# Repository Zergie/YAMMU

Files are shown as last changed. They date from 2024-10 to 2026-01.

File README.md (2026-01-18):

 <!--![GitHub Release](https://img.shields.io/github/v/release/Zergie/YAMMU)-->
Discord Shield (https://discord.gg/QSjW5CMHZC)



# Yet Another MMU
"Eight Materials, Twin Drawers, One Enclosure."

A Multi-Material Unit (MMU) for eight filaments that can also function as a filament dryer, keeping them dry while printing. The design is heavily inspired by Voron and their printers.

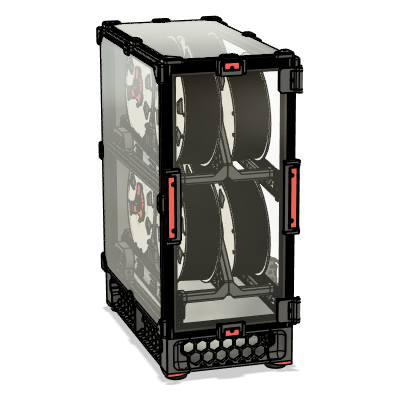
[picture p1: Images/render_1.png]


# Introduction
Currently, this project aims to support loading and unloading filament before a print begins. While it is technically possible to use this version for multi-color or multi-material prints, this is not our focus at the moment. We plan to support both options in the future, once we have a reliable working prototype.

# Features
- Multi-Material Unit for FFF
- Filament loading and unloading via powerful BLDC motors
- Enclosed Heated Filament Storage Built with 2020 Extrusion
- Separate electronics bay, similar to the one in the Voron 2.4
- Strongly inspired by the Voron 2.4 and Trident, this design seamlessly blends in when placed next to a Voron printer. Additionally, it supports the use of Voron user modifications.

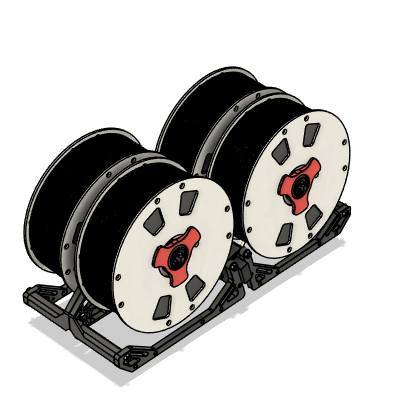
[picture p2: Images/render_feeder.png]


The YAMMU system features two identical feeders that take inspiration from Baboo Labs' "First Stage Loader." A key design advantage is the relatively short inlet tube, which simplifies the filament loading process and makes it exceptionally convenient. This practical design element sets it apart from other MMUs, as these feeders not only handle the initial loading of the filament but also seamlessly guide it directly into the extruder. As a result of this integrated functionality, a relatively large BLDC motor is required to ensure efficient operation and maintain consistent performance throughout the filament loading process. This approach not only enhances the user experience but also contributes to the overall reliability and effectiveness of the system.

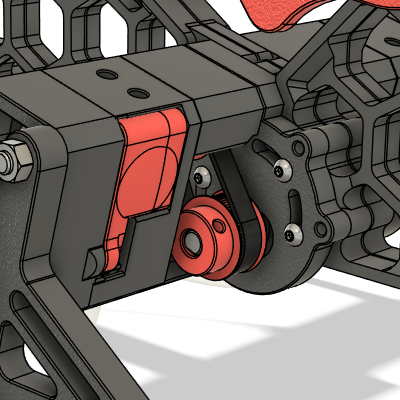
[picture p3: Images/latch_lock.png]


The filament is operated by two micro servos, which provide precise control and adjustability. These micro servos ensure that the filament functions efficiently and reliably. By utilizing these servos, the system achieves a high level of performance, making it suitable for various applications.

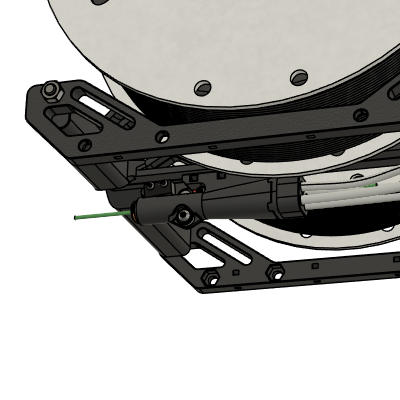
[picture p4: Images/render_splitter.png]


After passing through the feeder, the filament reaches the splitter. This component contains a filament switch that is triggered when a filament is present. If the switch does not trigger after loading a filament, it indicates a problem, and we can halt the print. Once any potential problems are cleared, the print can then be resumed.

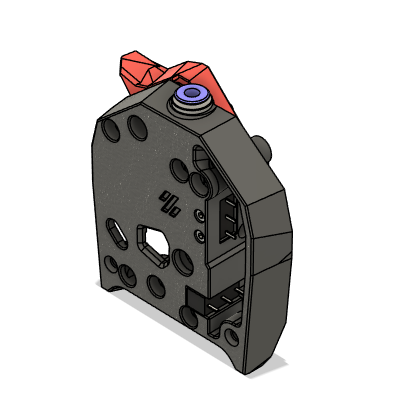
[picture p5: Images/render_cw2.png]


Last stage for loading filament is the tool head. Here a filament sensor must be present so the YAMMU knows when to switch off the BLDC motor. A suitable modification for the Stealthburner / Clockwork 2 can be found [here](https://github.com/Enraged-Rabbit-Community/ERCF_v2/blob/master/Recommended_Options/Toolhead_Modifications/Stls/1_Toolhead_And_Entry_Sensors/SB_CW2_Body.stl) or [a modified version here](STLs/Toolhead_Modifications).

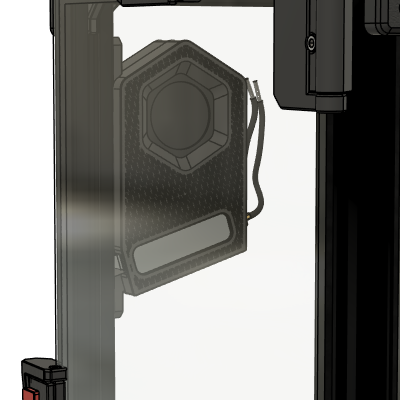
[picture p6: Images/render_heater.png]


Naturally, the filament chamber is meticulously sealed to ensure optimal conditions, and it is precisely heated to maintain the necessary temperature for efficient operation.

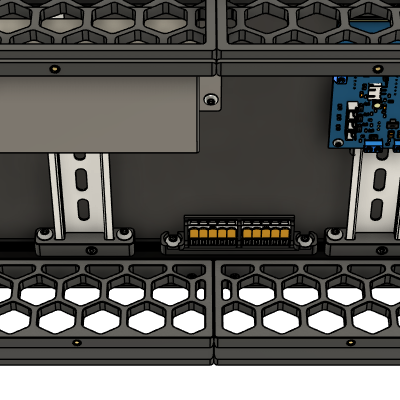
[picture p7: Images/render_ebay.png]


And all electronic components are organized in an electronics bay, much like the design of a Voron printer.

# Electronics
For YAMMU, we require a significant number of PWM ports along with several inputs for RPM, filament sensors, and other components. Currently, there's no available mainboard that meets all these requirements.
So, we've decided to take matters into our own hands and build our own MCU. Imagine it as a specialized hub, tailored just for us — packed with all the essential features we need for our project.
It's going to be custom-made to fit our specific needs, ensuring we have everything required to innovate without compromise.

[oshwlab.com](https://oshwlab.com/tpuchinger/mmu-control-board-v3-1)

# Current state
We are currently gearing up to release the first teaser, version 0.1. At this stage, not everything is running smoothly just yet, so we could really use your help! If you have skills in CAD, electronics, coding, or if you simply have a few hours to spare for testing the current iteration, we'd love to hear from you.

Your input and feedback can make a huge difference, and we’re excited to have the community involved in this journey. Feel free to reach out to me directly if you're interested in contributing. And if you're comfortable with GitHub, pull requests are also more than welcome!

## v1.0


- Manual Loading, e.g. Loading and Unloading filament before a print is started
- Automatic Loading, e.g. Loading and Unloading filament at the start of a print, for example as a "Filament Start Gcode" in OrcaSlicer
- Heating the Chamber for Drying Filament
- Electronics on Custom PCB

## v2.0


- All of the above
- Supporting the Extruder via the BLDC motor. When the extruder pulls the filament, the BLDC motor pushes it, and vice versa.

# Help needed
We're on the lookout for some awesome people to join our project and give us a hand with a few exciting tasks. If you're into testing, we'd love your help to make sure everything's running smoothly. Got a flair for electronics? Perfect! We could use your expertise to innovate and troubleshoot some cool hardware. And if writing is your thing, we could definitely use some help creating clear and engaging documentation. Whether you're a pro or just keen to dive in and learn, we'd be thrilled to have you onboard to help us keep things moving!

# Used Open Source Parts
- Parts from [Voron Trident](https://github.com/VoronDesign/Voron-Trident)
by Voron Design is licensed under the GNU GENERAL PUBLIC LICENSE Version 3
- Parts from [ERCF v2](https://github.com/Enraged-Rabbit-Community/ERCF_v2)
by Enraged Rabbit Community is licensed under the GNU GENERAL PUBLIC LICENSE Version 3
- Parts from [Stronger Compact Spool Auto-Rewinder](https://www.printables.com/model/784434-stronger-compact-spool-auto-rewinder)
by rans_1668459 is licensed under the GNU GENERAL PUBLIC LICENSE Version 2.
- Parts from [Voron 2.4 Front Panel Handle, Hinge & Magnet Latch](https://www.printables.com/model/371692-voron-24-front-panel-handle-hinge-magnet-latch/files)
by Jason_116929 is licensed under the Creative Commons - Attribution - Share Alike license.
- Parts from [Kit for Removable Panels/Doors for Voron V2/Trident using Strong Snap Latch](https://www.printables.com/model/702768-kit-for-removable-panelsdoors-for-voron-v2trident-/files)
by Victor Mateus Oliveira is licensed under the GNU GENERAL PUBLIC LICENSE Version 3
- Parts from [WAGO 221-415 extrusion mount](https://www.printables.com/model/869020-wago-221-415-extrusion-mount-1by5-and-2by5)
by Artxime is licensed under the GNU GENERAL PUBLIC LICENSE Version 3
- Parts from []()
by #### is licensed under the ####.

# Keep Browsing
Is YAMMU not the ideal MMU for you? Consider these alternatives:
- [ERCF v2](https://github.com/Enraged-Rabbit-Community/ERCF_v2): ERCF V1.1 served as my original MMU and inspired the development of YAMMU.
- [8-Track](https://github.com/ArmoredTurtle/8-Track-Raven-Alpha)
- [Primitive Infinite Spool System](https://github.com/Esoterical/PrinterMods/tree/main/Primitive%20Infinite%20Spool%20System)
- [TradRack](https://github.com/Annex-Engineering/TradRack)
- Prusa MMU3

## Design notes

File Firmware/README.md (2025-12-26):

# Build and Flash Firmware Image

1. Refer to [klipper's official installation](https://www.klipper3d.org/Installation.html)

2. `Building the micro-controller` with the configuration shown below.
  * [*] Enable extra low-level configuration options
  * Micro-controller Architecture = `Raspberry Pi RP2040/RP235x`
  * IF USE BOOTLOADER ([see klipper docs](https://www.klipper3d.org/Bootloaders.html#stm32f103-micro-controllers-blue-pill-devices))
    * Bootloader offset = `offset of your bootloader`
  * ELSE
    * Bootloader offset = `No bootloader`
  * Communication interface = `USBSERIAL`



3. Once the configuration is selected, press `q` to exit,  and "Yes" when  asked to save the configuration.
4. Run the command `make`
5. Flash the MCU
   * IF USE BOOTLOADER
     * Follow the instructions of your bootloader
   * ELSE IF USE NO BOOTLOADER
     * Unplug the Raspberry Pi
     * Hold `Boot` and plug in the Raspberry Pi
     * Run the command `make serialflash FLASH_DEVICE=/dev/serial/by-id/<YOUR USB ID>` for flashing via Serial or
     * OR Copy `~/klipper/out/klipper.uf2` via a windows pc

# Basic configuration
1. Run the `ls /dev/serial/by-id/*` command to get the correct ID number of the RP2040, and set the ID in `mmu.cfg`.
    ```
    [mcu]
    serial: /dev/serial/by-id/usb-1a86_USB_Serial-if00-port0
    restart_method: command
    ```
2. Refer to [klipper's official Config_Reference](https://www.klipper3d.org/Config_Reference.html) to configure the features you want.
3. Refer to [happy-hare's installation guide](https://github.com/moggieuk/Happy-Hare/wiki/Installation) to configure the basic printer settings.
4. In your `mmu/mmu_vars.cfg`, set the `mmu_gear_rotation_distances` variable to `1` for all gaters, as shown below:
    ```
    mmu_gear_rotation_distances: [1, 1, 1, 1, 1, 1, 1, 1]
    ```

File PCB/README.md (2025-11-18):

# Current Version

The PCBs were created with EasyEDA. If possible use the ProjectLink and order the PCBs from there, if possible.
The files here may not be up to date.

# Features

- 6 Servo Ports with 6V Power
- 3x Fan Ports
- 2x BLDC Motor Ports
- 2x Thermister Ports
- 1x Heater Port
- 1x Analog Belay Port
- I2C Pin Header
- Neopixel RGB Header (with one Neopixel onboard)
- 12 V Power Input

## Soldering Assistant Tool
In EasyEda Pro, you can use the Soldering Assistant Tool. To find it, open your main PCB file, "PCB_1." Then, click on "Tools" and select "Soldering Assistant Tool."



[EasyEda Pro](https://pro.easyeda.com/editor#id=5c5aed2dd44f48b9a0c28280d7f15482)

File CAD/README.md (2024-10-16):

# Work in Progress
This is a work in progress. The Assembly is by far not finished.

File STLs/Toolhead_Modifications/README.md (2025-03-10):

# Original Version
The Original version from the ERCF project can be found [here](https://github.com/Enraged-Rabbit-Community/ERCF_v2/blob/master/Recommended_Options/Toolhead_Modifications/Stls/1_Toolhead_And_Entry_Sensors/SB_CW2_Body.stl).

# What is different?
- It uses 5.5 mm steel balls instead of 5.6 mm, which means we only need to purchase one size for this project.
- It does not use self-tapping screws. Instead, I opt for M2x16 bolts because I consistently encounter split layers with the smaller self-tapping screws.

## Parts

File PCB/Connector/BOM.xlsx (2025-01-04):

No. | Quantity | Comment | Designator | Footprint | Value | Manufacturer Part | Manufacturer | Supplier Part | Supplier
1 | 4 | B5B-XH-AM | CN1,CN2,CN3,CN4 | CONN-TH_B5B-XH-AM-LF-SN |  | B5B-XH-AM | JST | C5306531 | LCSC
2 | 4 | Solder Bridge | PA11,PA12,PA13,PA14 | 0402-BRIDGE
3 | 4 | 15H725053 | U14,U17,U23,U25 | CONN-SMD_15H725053 |  | 15H725053 | SAMZO(三佐) | C29780882 | LCSC
4 | 4 | Solder pad 5P | U16,U18,U24,U26 | Solder Pad

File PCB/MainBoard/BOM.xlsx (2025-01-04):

No. | Quantity | Comment | Designator | Footprint | Value | Manufacturer Part | Manufacturer | Supplier Part | Supplier
1 | 8 | B3B-XH-AM(LF)(SN) | Belay,EN0,EN1,EN2,EN3,EN4,EN5,RGB | CONN-TH_3P-P2.50_B3B-XH-AM-LF-SN |  | B3B-XH-AM(LF)(SN) | JST | C161870 | LCSC
2 | 13 | 100nF | C1,C4,C5,C19,C20,C23,C24,C25,C26,C27,C28,C29,C31 | C1206 |  | CL31B104KBCNNNC | SAMSUNG(三星) | C24497 | LCSC
3 | 4 | 10uF | C2,C3,C17,C18 | C1206 |  | CL31A106KBHNNNE | SAMSUNG(三星) | C13585 | LCSC
4 | 3 | 10nF | C7,C16,C30 | C1206 |  | 1206B103K500NT | FH(风华) | C1846 | LCSC
5 | 1 | 1uF | C21 | C0603 |  | CL10A105KO8NNNC | SAMSUNG(三星) | C1592 | LCSC
6 | 1 | 10uF | C22 | C0603 |  | CL10A106KP8NNNC | SAMSUNG(三星) | C19702 | LCSC
7 | 4 | SS34_C8678 | D1,D2,D4,D6 | SMA_L4.3-W2.6-LS5.2-RD |  | SS34 | MDD(辰达半导体) | C8678 | LCSC
8 | 5 | B2B-XH-A (LF)(SN) | FAN0,FAN1,FAN2,TH1,TH3 | CONN-TH_B2B-XH-A-LF-SN |  | B2B-XH-A(LF)(SN) | JST | C158012 | LCSC
9 | 1 | 1125-1104G0S118C005 | I2C | HDR-TH_4P-P2.54-V-M |  | 1125-1104G0S118C005 | Wcon(维峰电子) | C721444 | LCSC
10 | 11 | 0805G (Green) | LED1,LED13,LED14,LED15,LED16,LED17,MF,MF2,MF3,MF5,PWR | LED0805-R-RD |  | KT-0805G | KENTO | C2297 | LCSC
11 | 1 | SKC6812RGBW-WS | LED12 | LED-SMD_4P-4.9-W4.9-LS5.0-BR |  | SKC6812RGBW-WS | 欧思科光电 | C5378724 | LCSC
12 | 2 | B5B-XH-AM(LF)(SN) | Motor1,Motor2 | CONN-TH_5P-P2.50_JST_B5B-XH-A-M |  | B5B-XH-AM(LF)(SN) | JST | C161872 | LCSC
13 | 2 | Solder Bridge | PA11,PA12 | 0402-BRIDGE
14 | 4 | AO3400A | Q1,Q2,Q3,Q8 | SOT-23-3_L2.9-W1.3-P1.90-LS2.4-BR |  | AO3400A | AOS | C20917 | LCSC
15 | 1 | BSS138 | Q6 | SOT-23-3_L2.9-W1.3-P1.90-LS2.4-BR |  | BSS138 | 宏迦橙 | C7420339 | LCSC
16 | 1 | 1kΩ | R1 | R0805 |  | 0805W8F1001T5E | UNI-ROYAL(厚声) | C17513 | LCSC
17 | 6 | 4.7kΩ | R2,R36,R38,R40,R42,R44 | R0805 | 4.7kΩ | 0805W8F4701T5E | UNI-ROYAL(厚声) | C17673 | LCSC
18 | 18 | 10kΩ | R3,R7,R9,R29,R30,R31,R32,R37,R39,R41,R43,R45,R48,R50,R53,R58,R59,R60 | R0805 |  | 0805W8F1002T5E | UNI-ROYAL(厚声) | C17414 | LCSC
19 | 4 | 10Ω | R4,R6,R8,R55 | R0805_NEW | 10Ω | 0805W8F100JT5E | UNI-ROYAL(厚声) | C17415 | LCSC
20 | 3 | 4.7kΩ | R5,R24,R46 | R0805 |  | 0805W8F4701T5E | UNI-ROYAL(Uniroyal Elec) | C17673 | LCSC
21 | 2 | 5.1kΩ | R33,R34 | R0805 |  | 0805W8F5101T5E | UNI-ROYAL(厚声) | C27834 | LCSC
22 | 2 | 1MΩ | R54,R57 | R0805 | 1MΩ | 0805W8F1004T5E | UNI-ROYAL(厚声) | C17514 | LCSC
23 | 1 | 470Ω | R61 | R0805 | 470Ω | 0805W8F4700T5E | UNI-ROYAL(厚声) | C17710 | LCSC
24 | 1 | STM32 Blue Pill | STM32 | STM32 BLUE PILL COPY |  | ?
25 | 1 | AMS1117-5.0 | U1 | SOT-223_L6.5-W3.5-P2.30-LS7.0-BR |  | AMS1117-5.0 | AMS | C6187 | LCSC
26 | 2 | JL301-50002U02 | U2,U6 | CONN-TH_2P-P2.54_JL301-50002U02 |  | JL301-50002U02 | JILN(锦凌) | C395214 | LCSC
27 | 1 | IRF540N_C5121605 | U3 | TO-220AB-3_L10.4-W4.6-P2.54-L |  | IRF540N | minos(迈诺斯) | C5121605 | LCSC
28 | 1 | L7806CV_C443685 | U4 | TO-220-3_L10.0-W4.5-P2.54-L |  | L7806CV | UMW(友台半导体) | C443685 | LCSC
29 | 6 | GPHA101-0302A001A1BA | U5,U7,U9,U11,U18,U19 | HDR-TH_3P-P2.54-V-M |  | GPHA101-0302A001A1BA | GREENCONN(格康) | C7434480 | LCSC
30 | 1 | LTC4311CSC6#TRPBF | U12 | SC-70-6_L2.1-W1.3-P0.65-LS2.1-BR |  | LTC4311CSC6#TRPBF | ADI(亚德诺) | C580856 | LCSC
31 | 1 | CH340K_C18208922 | U13 | ESOP-10_L4.9-W3.9-P1.00-LS6.0-BL-EP |  | CH340K | WCH(南京沁恒) | C18208922 | LCSC
32 | 1 | GT-USB-7010ASV | U14 | USB-C-SMD_G-SWITCH_GT-USB-7010ASV |  | GT-USB-7010ASV | G-Switch(品赞) | C2988369 | LCSC

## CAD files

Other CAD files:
Drawings_DXFs/Carbon Fiber Paper - Top - Bottom.dxf
STLs/BackGrill/back_grill_mount.stl
STLs/ElectronicsBay/Nut5/wago_mount.stl
STLs/ElectronicsBay/Nut6/DIN_frame_mount_x4.stl
STLs/ElectronicsBay/pcb_spacer_x4.stl
STLs/Feeder/motor_housing_c_x2.stl
STLs/Frame/Nut5/blind_joint_plug_I_x20.stl
STLs/Frame/Nut6/blind_joint_plug_x22.stl
STLs/Heater_200/heater_case_lower.stl
STLs/Panels/bottom_panel_hinge_x2.stl
STLs/Panels/Double_Pane/midspan_clip_10mm_x15.stl
STLs/Panels/Front_Doors/door_hinge_a_x2.stl
STLs/Panels/Single_Pane/corner_clip_6mm_x16.stl
STLs/Skirt/[a]_corner_baseplate_a_x2.stl
STLs/Skirt/Nut5/PSU.stl
STLs/Skirt/Nut6/front_skirt.stl
STLs/SpoolCarrier/Ptfe_Splitter/ptfe_sleeve_x8.stl
STLs/SpoolCarrier/Rewinder/inteface_x8.stl
Drawings_DXFs/Carbon Fiber Paper - Side A.dxf
Drawings_DXFs/Carbon Fiber Paper - Side B.dxf
Drawings_DXFs/Panels - Back.dxf
Drawings_DXFs/Panels - Bottom.dxf
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

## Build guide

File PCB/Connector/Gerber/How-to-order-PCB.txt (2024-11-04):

How to Order PCB

Please refer to:
https://prodocs.easyeda.com/en/pcb/order-order-pcb/index.html

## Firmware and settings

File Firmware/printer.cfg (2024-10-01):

[include fluidd.cfg]
[mcu]
serial: /dev/serial/by-id/usb-1a86_USB_Serial-if00-port0
restart_method: command

[virtual_sdcard]
path: /home/user/printer_data/gcodes
on_error_gcode: CANCEL_PRINT

[respond]
default_type: echo

[printer]
kinematics: none
max_velocity: 1000
max_accel: 1000

[gcode_button MMU_Endstop0]
pin: !mcu:PB14
press_gcode:   _MMU ENDSTOP=0 VALUE=1
release_gcode: _MMU ENDSTOP=0 VALUE=0
[gcode_button MMU_Endstop1]
pin: !mcu:PB13
press_gcode:   _MMU ENDSTOP=1 VALUE=1
release_gcode: _MMU ENDSTOP=1 VALUE=0
[gcode_button MMU_Endstop2]
pin: !mcu:PB15
press_gcode:   _MMU ENDSTOP=2 VALUE=1
release_gcode: _MMU ENDSTOP=2 VALUE=0
[gcode_button MMU_Endstop3]
pin: !mcu:PA8
press_gcode:   _MMU ENDSTOP=3 VALUE=1
release_gcode: _MMU ENDSTOP=3 VALUE=0
# [gcode_button MMU_Endstop4]
# pin: !mcu:
# press_gcode:   _MMU ENDSTOP=4 VALUE=1
# release_gcode: _MMU ENDSTOP=4 VALUE=0
# [gcode_button MMU_Endstop5]
# pin: !mcu:
# press_gcode:   _MMU ENDSTOP=5 VALUE=1
# release_gcode: _MMU ENDSTOP=5 VALUE=0
# [gcode_button MMU_Endstop6]
# pin: !mcu:
# press_gcode:   _MMU ENDSTOP=6 VALUE=1
# release_gcode: _MMU ENDSTOP=6 VALUE=0
# [gcode_button MMU_Endstop7]
# pin: !mcu:
# press_gcode:   _MMU ENDSTOP=7 VALUE=1
# release_gcode: _MMU ENDSTOP=7 VALUE=0
[gcode_button MMU_Endstop8]
pin: !mcu:PB12
press_gcode:   _MMU ENDSTOP=8 VALUE=1
release_gcode: _MMU ENDSTOP=8 VALUE=0
# [filament_switch_sensor fss]
# switch_pin: !mcu:PB12
# insert_gcode: _MMU ENDSTOP=4 VALUE=1
# runout_gcode: _MMU ENDSTOP=4 VALUE=0

[servo MMU_SERVO01] # servo for selecting filament 0 & 1
pin: mcu:PA0
initial_angle: 90
# [servo MMU_SERVO23] # servo for selecting filament 2 & 3
# pin: mcu:
# initial_angle: 90
# [servo MMU_SERVO45] # servo for selecting filament 4 & 5
# pin: mcu:
# initial_angle: 90
# [servo MMU_SERVO67] # servo for selecting filament 6 & 7
# pin: mcu:
# initial_angle: 90

# [output_pin MMU_SPEED04] # BLDC speed control for filament 0-4
# pin: mcu:PA1
# pwm: True
# hardware_pwm: True
# cycle_time: 0.00005 # 20 kHz (motor pwm range: 15 - 25 kHz)

[fan_generic MMU_SPEED04] # BLDC speed control for filament 0-4
pin: mcu:PA1
cycle_time: 0.00005 # 20 kHz (motor pwm range: 15 - 25 kHz)
hardware_pwm: True
kick_start_time: 0.0
tachometer_pin: mcu:PA11
tachometer_ppr: 90 # ppr is 9, but i want to see the rpm on the output shaft
tachometer_poll_interval: 0.0002

# [output_pin MMU_SPEED57] # BLDC speed control for filament 5-7
# pin: mcu:PA2
# cycle_time: 0.00005 # 20 kHz (motor pwm range: 15 - 25 kHz)
# hardware_pwm: True
# kick_start_time: 0.0
# tachometer_pin: mcu:PA12
# tachometer_ppr: 90 # ppr is 9, but i want to see the rpm on the output shaft
# tachometer_poll_interval: 0.0002

[output_pin MMU_DIR] # BLDC direction control for all filaments
pin: mcu:PB9


# [heater_generic MMU_HEATER]
# gcode_id: MMU_HEATER
# heater_pin: 
# sensor_type: Generic 3950
# sensor_pin: mcu:PB1
# control: pid
# pid_Kp: 49.034 
# pid_Ki: 2.224 
# pid_Kd: 270.296
# min_temp: 0
# max_temp: 100

# [controller_fan MMU_FAN]
# pin: 
# heater: MMU_HEATER
# fan_speed: 1.0
# idle_timeout: 30
# idle_speed: 1.0







[gcode_macro TEST]
description: GCode for debuging the MMU
gcode:
    RESPOND MSG="ENDSTOP0: {printer["gcode_macro _MMU"].endstop0}"
    RESPOND MSG="ENDSTOP1: {printer["gcode_macro _MMU"].endstop1}"
    RESPOND MSG="ENDSTOP2: {printer["gcode_macro _MMU"].endstop2}"
    RESPOND MSG="ENDSTOP3: {printer["gcode_macro _MMU"].endstop3}"

[delayed_gcode MMU_TIMEOUT]
# Timeout, that guards all MMU functions.
gcode:
    MMU_MOVE TOOL=-1 SPEED=0.0
    SET_GCODE_VARIABLE MACRO=_MMU VARIABLE=action VALUE="''"
    RESPOND TYPE=error MSG="MMU_TIMEOUT"

[delayed_gcode MMU_STOP]
gcode:
    MMU_MOVE SPEED=0.0

[gcode_macro _MMU]
description: State machine for interacting with the MMU
variable_home_timeout: 10.0
variable_home_speed: 0.33 # retraction speed used for homeing
variable_load_timeout: 10.0
variable_load_speeds: (1.0, 5500, 0.2) # (<speed>, <duration>, ..., <speed>)
variable_unload_speed: 1.0
variable_eject_duration: 1.0
variable_action: ""
variable_endstop0: 0
variable_endstop1: 0
variable_endstop2: 0
variable_endstop3: 0
variable_endstop4: 0
variable_endstop5: 0
variable_endstop6: 0
variable_endstop7: 0
variable_endstop8: 0
gcode:
    RESPOND MSG="_MMU {rawparams} (Action={printer["gcode_macro _MMU"].action})"

    {% if 'ENDSTOP' in params %}
        {% set endstop = params.ENDSTOP|int %}
        {% set value   = params.VALUE|int %}
        SET_GCODE_VARIABLE MACRO=_MMU VARIABLE={"endstop" ~ endstop} VALUE={value}

        {% if printer["gcode_macro _MMU"].action != "" %}
            {% set action = printer["gcode_macro _MMU"].action.split(":")[0] %}
            {% set tool   = printer["gcode_macro _MMU"].action.split(":")[1]|int %}
            {% set phase  = printer["gcode_macro _MMU"].action.split(":")[2]|int %}

            {% if action == "HOME" %}
                # todo: check what endstop is triggerd. When <endstop> != <tool> there is an error in the configuration
                #       e.g. motor position 0 pushes filament to endstop 1 
                {% if phase == 1 %}
                    SET_GCODE_VARIABLE MACRO=_MMU VARIABLE=action VALUE="'{action}:{tool}:{phase + 1}'"
                    UPDATE_DELAYED_GCODE ID=MMU_TIMEOUT DURATION={printer["gcode_macro _MMU"].home_timeout}
                    MMU_MOVE TOOL={tool} SPEED=-{printer["gcode_macro _MMU"].home_speed}
                {% else %}
                    SET_GCODE_VARIABLE MACRO=_MMU VARIABLE=action VALUE="''"
                    MMU_MOVE TOOL=-1 SPEED=0.0
                    RESPOND MSG="Tool {tool} homed."
                    UPDATE_DELAYED_GCODE ID=MMU_TIMEOUT DURATION=0
                {% endif %}
            {% elif action == "LOAD" %}
                {% if phase == 1 %}
                    SET_GCODE_VARIABLE MACRO=_MMU VARIABLE=action VALUE="'{action}:{tool}:{phase + 1}'"
                    MMU_MOVE TOOL={endstop} SPEED={printer["gcode_macro _MMU"].load_speeds[0]}
                {% elif phase == 2 %}
                    SET_GCODE_VARIABLE MACRO=_MMU VARIABLE=action VALUE="'{action}:{tool}:{phase + 1}'"
                    MMU_MOVE TOOL={endstop} SPEED=-{printer["gcode_macro _MMU"].home_speed}
                {% elif phase == 3 %}
                    SET_GCODE_VARIABLE MACRO=_MMU VARIABLE=action VALUE="''"
                    MMU_MOVE TOOL=-1 SPEED=0.0
                    MMU_LOAD TOOL={tool}
                {% elif endstop == 8 %}
                    SET_GCODE_VARIABLE MACRO=_MMU VARIABLE=action VALUE="''"
                    UPDATE_DELAYED_GCODE ID=MMU_TIMEOUT DURATION=0
                    MMU_MOVE TOOL=-1 SPEED=0.0
                {% endif %}
            {% elif action == "UNLOAD" %}
                {% if endstop == 8 %}
                {% elif phase == 1 %}
                    SET_GCODE_VARIABLE MACRO=_MMU VARIABLE=action VALUE="'{action}:{tool}:{phase + 1}'"
                    UPDATE_DELAYED_GCODE ID=MMU_TIMEOUT DURATION={printer["gcode_macro _MMU"].home_timeout}
                    MMU_MOVE TOOL={TOOL} SPEED={printer["gcode_macro _MMU"].home_speed}
                {% elif phase == 2 %}
                    SET_GCODE_VARIABLE MACRO=_MMU VARIABLE=action VALUE="'{action}:{tool}:{phase + 1}'"
                    UPDATE_DELAYED_GCODE ID=MMU_TIMEOUT DURATION={printer["gcode_macro _MMU"].home_timeout}
                    MMU_MOVE TOOL={TOOL} SPEED=-{printer["gcode_macro _MMU"].home_speed}
                {% else %}
                    SET_GCODE_VARIABLE MACRO=_MMU VARIABLE=action VALUE="''"
                    MMU_MOVE TOOL=-1 SPEED=0.0
                    RESPOND MSG="Tool {tool} unloaded."
                    UPDATE_DELAYED_GCODE ID=MMU_TIMEOUT DURATION=0
                {% endif %}
            {% elif action == "EJECT" %}
                SET_GCODE_VARIABLE MACRO=_MMU VARIABLE=action VALUE="''"
                UPDATE_DELAYED_GCODE ID=MMU_TIMEOUT DURATION=0
                MMU_EJECT TOOL={tool}
            {% else %}
                SET_GCODE_VARIABLE MACRO=_MMU VARIABLE=action VALUE="''"
            {% endif %}
        {% endif %}
    {% endif %}
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

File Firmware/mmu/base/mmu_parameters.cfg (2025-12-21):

########################################################################################################################
# Happy Hare MMU Software
#
# Template file for MMU's with Virtual Selector (Type-B designs like Box Turtle, Night Owl, Angry Beaver, ...)
# This file omits selector and selector-servo configuration and a few other options that don't make sense
#
# EDIT THIS FILE BASED ON YOUR SETUP
#
# Copyright (C) 2022-2025  moggieuk#6538 (discord)
#                          moggieuk@hotmail.com
# This file may be distributed under the terms of the GNU GPLv3 license.
#
# Goal: Main configuration parameters for the klipper module
#
# (\_/)
# ( *,*)
# (")_(") Happy Hare Ready
#
# Notes:
#   Macro configuration is specified separately in 'mmu_macro_vars.cfg'.
#   Full details in https://github.com/moggieuk/Happy-Hare/tree/main/doc/configuration.md
#
[mmu]
happy_hare_version: 3.41			# Don't mess, used for upgrade detection

# MMU Hardware Limits --------------------------------------------------------------------------------------------------
# ██╗     ██╗███╗   ███╗██╗████████╗███████╗
# ██║     ██║████╗ ████║██║╚══██╔══╝██╔════╝
# ██║     ██║██╔████╔██║██║   ██║   ███████╗
# ██║     ██║██║╚██╔╝██║██║   ██║   ╚════██║
# ███████╗██║██║ ╚═╝ ██║██║   ██║   ███████║
# ╚══════╝╚═╝╚═╝     ╚═╝╚═╝   ╚═╝   ╚══════╝
#
# Define the physical limits of your MMU. These settings will be respected regardless of individual speed settings.
#
gear_max_velocity: 300			# Never to be exceeded gear velocity regardless of specific parameters
gear_max_accel: 1500			# Never to be exceeded gear acceleration regardless of specific parameters


# Logging --------------------------------------------------------------------------------------------------------------
# ██╗      ██████╗  ██████╗  ██████╗ ██╗███╗   ██╗ ██████╗
# ██║     ██╔═══██╗██╔════╝ ██╔════╝ ██║████╗  ██║██╔════╝
# ██║     ██║   ██║██║  ███╗██║  ███╗██║██╔██╗ ██║██║  ███╗
# ██║     ██║   ██║██║   ██║██║   ██║██║██║╚██╗██║██║   ██║
# ███████╗╚██████╔╝╚██████╔╝╚██████╔╝██║██║ ╚████║╚██████╔╝
# ╚══════╝ ╚═════╝  ╚═════╝  ╚═════╝ ╚═╝╚═╝  ╚═══╝ ╚═════╝
#
# log_level & logfile_level can be set to one of (0 = essential, 1 = info, 2 = debug, 3 = trace, 4 = stepper moves)
# Generally you can keep console logging to a minimal whilst still sending debug output to the mmu.log file
# Increasing the console log level is only really useful during initial setup to save having to constantly open the log file
# Note: that it is not recommended to keep logging at level greater that 2 (debug) if not debugging an issue because
# of the additional overhead
#
log_level: 1
log_file_level: 2			# Can also be set to -1 to disable log file completely
log_statistics: 1 			# 1 to log statistics on every toolchange (default), 0 to disable (but still recorded)
log_visual: 1				# 1 log visual representation of filament, 0 = disable
log_startup_status: 1			# Whether to log tool to gate status on startup, 1 = summary (default), 0 = disable
log_m117_messages: 1			# Whether send toolchange message via M117 to screen


# Movement speeds ------------------------------------------------------------------------------------------------------
# ███████╗██████╗ ███████╗███████╗██████╗ ███████╗
# ██╔════╝██╔══██╗██╔════╝██╔════╝██╔══██╗██╔════╝
# ███████╗██████╔╝█████╗  █████╗  ██║  ██║███████╗
# ╚════██║██╔═══╝ ██╔══╝  ██╔══╝  ██║  ██║╚════██║
# ███████║██║     ███████╗███████╗██████╔╝███████║
# ╚══════╝╚═╝     ╚══════╝╚══════╝╚═════╝ ╚══════╝
#
# Long moves are faster than the small ones and used for the bulk of the bowden movement. You can set two fast load speeds
# depending on whether pulling from the spool or filament buffer (if fitted and not the first time load). This can be helpful
# in allowing faster loading from buffer and slower when pulling from the spool because of the additional friction (prevents
# loosing steps). Unloading speed can be tuning if you have a rewinder system that imposes additional limits.
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

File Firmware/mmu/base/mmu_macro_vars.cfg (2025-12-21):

########################################################################################################################
# Happy Hare MMU Software
#
# EDIT THIS FILE BASED ON YOUR SETUP
#
# Copyright (C) 2022-2025  moggieuk#6538 (discord)
#                          moggieuk@hotmail.com
# This file may be distributed under the terms of the GNU GPLv3 license.
#
# Goal: Happy Hare supporting MACRO configuration
#
# (\_/)
# ( *,*)
# (")_(") Happy Hare Ready
#
#
# Supporting set of macros supplied with Happy Hare can be customized by editing the macro "variables" declared here.
#
# This configuration will automatically retained and upgraded between releases (a backup of previous config files will
# always be made for your reference). If you want to customize macros beyond what is possible through these variables
# it is highly recommended you copy the macro to a new name and change the callback macro name in 'mmu_parameters.cfg'
# That way the default macros can still be upgraded but your customization will be left intact
#


# PERSISTED STATE ---------------------------------------------------------
# Happy Hare stores configuration and state in the klipper variables file.
# Since klipper can only be a single 'save_variables' file, if you already
# have one you will need to merge the two and point this appropriately.
#
[save_variables]
filename: ~/printer_data/config/mmu/mmu_vars.cfg


# NECESSARY KLIPPER OVERRIDES ---------------------------------------------
# ██╗  ██╗██╗     ██╗██████╗ ██████╗ ███████╗██████╗ 
# ██║ ██╔╝██║     ██║██╔══██╗██╔══██╗██╔════╝██╔══██╗
# █████╔╝ ██║     ██║██████╔╝██████╔╝█████╗  ██████╔╝
# ██╔═██╗ ██║     ██║██╔═══╝ ██╔═══╝ ██╔══╝  ██╔══██╗
# ██║  ██╗███████╗██║██║     ██║     ███████╗██║  ██║
# ╚═╝  ╚═╝╚══════╝╚═╝╚═╝     ╚═╝     ╚══════╝╚═╝  ╚═╝
#
# These supplemental settings essentially disable klipper's built in
# extrusion limits and is necessary when using an MMU
[extruder]
max_extrude_only_distance: 200
max_extrude_cross_section: 50

# For dialog prompts and progress in Mainsail. Requires Mainsail version >= v2.9.0
[respond]

# Other Happy Hare prerequisites. Harmless if already defined elsewhere in user config
[display_status]
[pause_resume]
[virtual_sdcard]
path: ~/printer_data/gcodes
#on_error_gcode: CANCEL_PRINT


# PRINT START/END ---------------------------------------------------------
# ██████╗ ██████╗ ██╗███╗   ██╗████████╗    ███████╗████████╗ █████╗ ██████╗ ████████╗
# ██╔══██╗██╔══██╗██║████╗  ██║╚══██╔══╝    ██╔════╝╚══██╔══╝██╔══██╗██╔══██╗╚══██╔══╝
# ██████╔╝██████╔╝██║██╔██╗ ██║   ██║       ███████╗   ██║   ███████║██████╔╝   ██║   
# ██╔═══╝ ██╔══██╗██║██║╚██╗██║   ██║       ╚════██║   ██║   ██╔══██║██╔══██╗   ██║   
# ██║     ██║  ██║██║██║ ╚████║   ██║       ███████║   ██║   ██║  ██║██║  ██║   ██║   
# ╚═╝     ╚═╝  ╚═╝╚═╝╚═╝  ╚═══╝   ╚═╝       ╚══════╝   ╚═╝   ╚═╝  ╚═╝╚═╝  ╚═╝   ╚═╝   
#   (base/mmu_software.cfg)
#
[gcode_macro _MMU_SOFTWARE_VARS]
description: Happy Hare optional configuration for print start/end checks
gcode: # Leave empty

# These variables control the behavior of the MMU_START_SETUP and MMU_START_LOAD_INITIAL_TOOL macros
variable_user_pre_initialize_extension      : ''	; Executed at start of MMU_START_SETUP. Commonly G28 to home
variable_home_mmu                           : False	; True/False, Whether to home mmu before print starts
variable_check_gates                        : True	; True/False, Whether to check filament is loaded in all gates used
variable_load_initial_tool                  : True	; True/False, Whether to automatically load initial tool
#
# Automapping strategy to apply slicer tool map to find matching MMU gate (will adjust tool-to-gate map). Options are:
#   'none'           - don't automap (i.e. don't update tool-to-gate map)
#   'filament_name'  - exactly match on case insensitive filament name
#   'material'       - exactly match on material
#   'color'          - exactly match on color (with same material)
#   'closest_color'  - match to closest available filament color (with same material)
#   'spool_id'       - exactly match on spool_id  [FUTURE]
variable_automap_strategy                   : "none"	; none|filament_name|material|color|closest_color|spool_id

# These variables control the behavior of the MMU_END macro
variable_user_print_end_extension           : ''	; Executed at start of MMU_END. Good place to move off print
variable_unload_tool                        : True	; True/False, Whether to unload the tool at the end of the print
variable_reset_ttg                          : False	; True/False, Whether reset TTG map at end of print
variable_dump_stats                         : True	; True/False, Whether to display print stats at end of print


# STATE MACHINE CHANGES ---------------------------------------------------
# ███████╗████████╗ █████╗ ████████╗███████╗     ██████╗██╗  ██╗ █████╗ ███╗   ██╗ ██████╗ ███████╗
# ██╔════╝╚══██╔══╝██╔══██╗╚══██╔══╝██╔════╝    ██╔════╝██║  ██║██╔══██╗████╗  ██║██╔════╝ ██╔════╝
# ███████╗   ██║   ███████║   ██║   █████╗      ██║     ███████║███████║██╔██╗ ██║██║  ███╗█████╗  
# ╚════██║   ██║   ██╔══██║   ██║   ██╔══╝      ██║     ██╔══██║██╔══██║██║╚██╗██║██║   ██║██╔══╝  
# ███████║   ██║   ██║  ██║   ██║   ███████╗    ╚██████╗██║  ██║██║  ██║██║ ╚████║╚██████╔╝███████╗
# ╚══════╝   ╚═╝   ╚═╝  ╚═╝   ╚═╝   ╚══════╝     ╚═════╝╚═╝  ╚═╝╚═╝  ╚═╝╚═╝  ╚═══╝ ╚═════╝ ╚══════╝
#   (base/mmu_state.cfg)
#
[gcode_macro _MMU_STATE_VARS]
description: Happy Hare configuration for state change hooks
gcode: # Leave empty

# You can extend functionality to all Happy Hare state change or event
# macros by adding a command (or call to your gcode macro).
# E.g for additional LED logic or consumption counters
variable_user_action_changed_extension      : ''	; Executed after default logic with duplicate params
variable_user_print_state_changed_extension : ''	; Executed after default logic with duplicate params
variable_user_mmu_event_extension           : ''	; Executed after default logic with duplicate params

# Maintenance warning limits (consumption counters)
variable_servo_down_limit                   : 5000      ; Set to -1 for no limit / disable warning
variable_cutter_blade_limit                 : 3000      ; Set to -1 for no limit / disable warning


# SEQUENCE MACRO - PARKING MOVEMENT AND TOOLCHANGE CONTROL ----------------
# ███╗   ███╗ ██████╗ ██╗   ██╗███████╗███╗   ███╗███████╗███╗   ██╗████████╗
# ████╗ ████║██╔═══██╗██║   ██║██╔════╝████╗ ████║██╔════╝████╗  ██║╚══██╔══╝
# ██╔████╔██║██║   ██║██║   ██║█████╗  ██╔████╔██║█████╗  ██╔██╗ ██║   ██║   
# ██║╚██╔╝██║██║   ██║╚██╗ ██╔╝██╔══╝  ██║╚██╔╝██║██╔══╝  ██║╚██╗██║   ██║   
# ██║ ╚═╝ ██║╚██████╔╝ ╚████╔╝ ███████╗██║ ╚═╝ ██║███████╗██║ ╚████║   ██║   
# ╚═╝     ╚═╝ ╚═════╝   ╚═══╝  ╚══════╝╚═╝     ╚═╝╚══════╝╚═╝  ╚═══╝   ╚═╝   
# Configure carefully if you 'enable_park: True'
#   (base/mmu_sequence.cfg)
#
[gcode_macro _MMU_SEQUENCE_VARS]
description: Happy Hare sequence macro configuration variables
gcode: # Leave empty
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

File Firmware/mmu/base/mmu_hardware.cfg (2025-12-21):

########################################################################################################################
# Happy Hare MMU Software
#
# EDIT THIS FILE BASED ON YOUR SETUP
#
# Copyright (C) 2022-2025  moggieuk#6538 (discord)
#                          moggieuk@hotmail.com
# This file may be distributed under the terms of the GNU GPLv3 license.
#
# Goal: Happy Hare MMU hardware config file with config for unknown MCU board
#
# (\_/)
# ( *,*)
# (")_(") Happy Hare Ready
#
#
# Notes about setup of common external MCUs can be found here:
#  https://github.com/moggieuk/Happy-Hare/blob/main/doc/mcu_notes.md
#
# Note about "touch" endstops: Happy Hare provides extremely flexible homing options using both single steppers or
# synced steppers. The "touch" option leverages stallguard and thus requires the appropriate 'diag_pin' and stallguard
# parameters set on the TMC driver section. If you have the diag_pin exposed, it is harmless to define this because
# they will only be used when explicitly needed and configured.
#
# Touch option for each stepper provides these benefits / possibilities (experimental):
#  - on extruder stepper allows for the automatic detection of the nozzle!
#  - on selector stepper allows for the automatic detection of filament stuck in the gate and subsequent recovery
#  - on gear stepper allows for the automatic detection of the extruder entrance
#
# In summary, "touch" homing with your MMU is an advanced option that requires patience and careful tuning. Everything
# works with regular endstops and there are workaround options for certain homing points (like extruder entry) in
# the absence of any endstop. I'm really interested in creative setups. Ping me on Discord (moggieuk#6538)
#
# See 'mmu.cfg' for serial definition and pins aliases
#
# HOMING CAPABLE EXTRUDER (VERY ADVANCED) -----------------------------------------------------------------------------
# With Happy Hare installed even the extruder can be homed. You will find the usual 'endstop' parameters can be added
# to your '[extruder]' section.  Useless you have some clever load cell attached to your nozzle it only really makes
# sense to configure stallguard style "touch" homing. To do this add lines similar to this to your existing
# '[extruder]' definition in printer.cfg.
#
#    [extruder]
#    endstop_pin: tmc2209_extruder:virtual_endstop
#
# Also be sure to add the appropriate stallguard config to the TMC section, e.g.
#
#    [tmc2209 extruder]
#    diag_pin: E_DIAG		# Set to MCU pin connected to TMC DIAG pin for extruder
#    driver_SGTHRS: 100		# 255 is most sensitive value, 0 is least sensitive
#
# Happy Hare will take care of the rest and add a 'mmu_ext_touch' endstop automatically
#

[duplicate_pin_override]
pins: EBBCan:PB7, EBBCan:PB5 # Extruder and toolhead sensor pins are shared with the mainboard

# MMU MACHINE / TYPE ---------------------------------------------------------------------------------------------------
# ███╗   ███╗███╗   ███╗██╗   ██╗    ███╗   ███╗ █████╗  ██████╗██╗  ██╗██╗███╗   ██╗███████╗
# ████╗ ████║████╗ ████║██║   ██║    ████╗ ████║██╔══██╗██╔════╝██║  ██║██║████╗  ██║██╔════╝
# ██╔████╔██║██╔████╔██║██║   ██║    ██╔████╔██║███████║██║     ███████║██║██╔██╗ ██║█████╗
# ██║╚██╔╝██║██║╚██╔╝██║██║   ██║    ██║╚██╔╝██║██╔══██║██║     ██╔══██║██║██║╚██╗██║██╔══╝
# ██║ ╚═╝ ██║██║ ╚═╝ ██║╚██████╔╝    ██║ ╚═╝ ██║██║  ██║╚██████╗██║  ██║██║██║ ╚████║███████╗
# ╚═╝     ╚═╝╚═╝     ╚═╝ ╚═════╝     ╚═╝     ╚═╝╚═╝  ╚═╝ ╚═════╝╚═╝  ╚═╝╚═╝╚═╝  ╚═══╝╚══════╝
[mmu_machine]

# Number of selectable gate on (each) MMU. Generally this is a single number, but with multi-mmu (type-B) setups
# it can be a comma separated list of the number of gates per unit.
# E.g. 'num_gates: 4,4,2' for a 2xBox Turtle and 1xNight Owl multiplexed setup
#
num_gates: 8
selector_type: MacroSelector

# MMU Vendor & Version is used to automatically configure some parameters and validate configuration
# If custom set to "Other" and uncomment the additional parameters below
#
# ERCF          1.1  add "s" suffix for Springy, "b" for Binky, "t" for Triple-Decky
#                    e.g. "1.1sb" for v1.1 with Springy mod and Binky encoder
# ERCF          2.0  community edition ERCFv2
# ERCF          2.5
# Tradrack      1.0  add "e" if encoder is fitted (assumed to be Binky)
# AngryBeaver   1.0
# BoxTurtle     1.0
# NightOwl      1.0
# 3MS           1.0
# 3D Chameleon  1.0
# Pico          1.0
# Prusa         3.0  NOT YET SUPPORTED - COMING SOON
# Other              Generic setup that may require further customization of 'cad' parameters. See doc in mmu_parameters.cfg
#
mmu_vendor: Other			# MMU family
mmu_version: 1.0			# MMU hardware version number (add mod suffix documented above)
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

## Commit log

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2024-09-29 Remove outdated PTFE Splitter v30.step and update ptfe_splitter.stl with latest design adjustments.
    [PTFE Splitter v30.step, ptfe_splitter.stl]
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2024-09-30 Add new DXF and STL files, update existing STL files, and remove obsolete Spool_Carrier.dxf
    [Blank.stl, PSU.stl, Spool_Carrier.dxf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]
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2024-09-30 Add new STL files for DIN center support and frame mounts for Nut5 and Nut6
    [DIN_center_support_x2.stl, DIN_frame_mount_x4.stl]
2024-09-30 Add new STL file for DIN corner frame mount (x4) in Nut6 directory
    [DIN_corner_frame_mount_x4.stl]
2024-10-01 Update printer.cfg: Adjust home speed, add MMU busy checks, and include TODOs for endstop validation.
    [printer.cfg]
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2024-10-02 Add new gear and spool support STL files; update motor housing STL file
    [motor_housing_a.stl, spool_support_x8.stl]
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2024-10-04 Update README and add new STL files for Nut5 and Nut6 mounts, modify existing STL files for improved design.
    [DIN_corner_frame_mount_x4.stl, DIN_frame_mount_x4.stl, wago_mount.stl]
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2024-10-04 Add cable frame anchor STL files for Nut5 and Nut6 in ElectronicsBay
    [cable_frame_anchor.stl]
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2024-10-16 Replace ptfe_splitter.stl with ptfe_splitter_x2.stl in SpoolCarrier directory.
    [ptfe_splitter.stl, ptfe_splitter_x2.stl]
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2024-10-31 Add STL files for Rewinder components: clutch, drive plate, end cap, hub, nut, and plates A & B
    [clutch_inner_x8.stl, clutch_outer_x8.stl, drive_plate_x8.stl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]
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2024-10-31 Update README.md with corrected STL link and add README for Toolhead Modifications directory
2024-10-31 Added unmodified parts from ERCF, so all parts that need to be printed are kept together.
    [SB_CW2_Plate.stl, [a]_SB_CW2_Latch.stl]
2024-11-01 Add new STL files for SpoolCarrier supports and pogo pin mounts; update SB_CW2_Body.stl in Toolhead_Modifications.
    [SB_CW2_Body.stl, back_support_l_x2.stl, back_support_r_x2.stl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]
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2024-11-05 Update STL files for SpoolCarrier Rewinder components: clutch, drive plate, and plates A & B.
    [clutch_inner_x8.stl, clutch_outer_x8.stl, drive_plate_x8.stl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]
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2024-11-20 Update README with new spool rewinder link and license. Add new STL files for spool carrier rewinder and remove outdated ones.
    [[a]_nut_x8.stl, bearing_holder_x8.stl, c-clip_x16.stl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]
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2024-11-20 Add STL processing functionality and improve error handling in Update-Files.ps1 script.
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2024-11-21 Enhance error handling and improve STL processing logic in Update-Files.ps1 script.
2024-11-21 Add STL files for Electronics Bay components: din_clip_x1, pcb_bracket, pcb_spacer_x4, and psu_bracket.
    [din_clip_x1.stl, pcb_bracket.stl, pcb_spacer_x4.stl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]
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2024-11-22 Add new middle support STL files and remove obsolete spool support file
    [middle_support_back_a_x2.stl, middle_support_back_b_x2.stl, middle_support_front_a_x2.stl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]
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2024-12-11 Update STL files and enhance Update-Files.ps1 script to handle duplicate file names and suppress error messages.
    [middle_support_back_a_x2.stl, middle_support_back_b_x2.stl]
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2024-12-31 Update STL files and improve Update-Files.ps1 script
    - Added check for STL dimensions exceeding 200x200 build plate.
    [support_a_mirror_x2.stl, support_a_x2.stl, support_b_mirror_x2.stl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]
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2025-01-03 Update STL files for middle supports and remove obsolete pogo pin mounts; modify Update-Files.ps1 script accordingly.
    [middle_support_back_a_x2.stl, middle_support_back_b_x2.stl, middle_support_front_a_x2.stl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]
2025-01-04 Add connector_support_x4.stl to SpoolCarrier and update Update-Files.ps1 to include 'Body.*\.stl$' in illegal file name checks.
    [connector_support_x4.stl]
2025-01-04 Refactor PCB directory structure: separate Connector and MainBoard files, update Gerber files, and modify README.md.
    [BOM.xlsx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]
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2025-02-16 Update STL files for SpoolCarrier: modified back_support_x4 and ptfe_splitter_x2, removed connector_support_x4 and din_rail_clip_x12, added din_rail_clip_x8, ptfe_coupler_x2, ptfe_din_rail_base_x2, a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
    [back_support_x4.stl, connector_support_x4.stl, din_rail_clip_x12.stl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]
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2025-02-24 Update PTFE splitter model and enhance Update-Files.ps1
    - Updated ptfe_splitter_x2.stl with new model version.
    - Introduced Copy-ToProjectFolder function to handle STL files from a temporary directory.
    - Refactored Update-Stl function to support optional suppression of file names in output.
    - Improved debug output and handling of large STL files in Update-Stl.
    - Adjusted output handling for unimplemented file types.
    [ptfe_splitter_x2.stl]
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2025-02-24 Update STL files for ptfe splitter and cap; modify filename pattern check in Update-Files.ps1 script.
    [ptfe_splitter_cap_x2.stl, ptfe_splitter_x2.stl]
2025-02-25 Update Update-Files.ps1 script: Remove unused variable declaration and streamline file processing logic.
    - Updated ptfe_splitter_cap_x2.stl and ptfe_splitter_x2.stl files with new versions and sizes.
    - Refactored Update-Files.ps1 script for improved readability and functionality
    [ptfe_splitter_cap_x2.stl, ptfe_splitter_x2.stl]
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2025-03-01 Add new STL files for connectors and end caps, update existing STL files with new versions, and modify Update-Files.ps1 to improve file handling logic and output conditions.
    [[a]_connector_a_x2.stl.stl, [a]_connector_b_x2.stl.stl, connector_x2.stl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]
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2025-03-01 Update STL files for feeder gear housing and motor housing components with new versions.
    [feeder_gear_housing_a.stl, feeder_gear_housing_b.stl, motor_housing_b.stl]
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2025-04-14 Added new STL files for BackGrill and Feeder components, updated and replaced several STL files for Feeder and SpoolCarrier, and modified the PowerShell script to improve STL file renaming and proces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
    [[a]_latch_lock_x4.stl, [a]_ptfe_splitter_cap_x2.stl, [a]latch_a_x4.stl(2).stl.stl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]
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2025-04-22 Replace belay_body.stl and belay_hat.stl with new belay_housing.stl and belay_poti_insert.stl files in the BackGrill directory.
    [belay_body.stl, belay_hat.stl, belay_housing.stl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]
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2025-07-08 Update FusionHeadless submodule and replace processed images with original versions. Add new STL files for feeder latches. Adjust Makefile to include new image dependencies and modify render settings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
    [latch_a.stl, latch_b.stl, latch_mirror_a.stl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]
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2025-07-10 Update CAD and Image files, modify Makefile, and remove obsolete script
    - Updated CAD/Assembly.zip with new content and reduced size.
    - Updated submodule FusionAddons/FusionHeadless to the latest commit.
    - Replaced several images in the Images directory with new versions.
    - Modified Makefile to include new targets and updated existing rules for better file management and rendering parameters.
    - Deleted Update-Files.ps1 script as it is no longer needed.
    [feeder_gear_housing_x4.stl, motor_housing_c_x2.stl]
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2025-11-18 Enhance Firmware Functionality and Remove Obsolete STL Files
    - Modified `Deploy-Project.ps1` to handle both "error" and "shutdown" states for firmware restart detection.
    - Enhanced `bldc.py` with additional features including debug messaging, motor direction handling, and improved RPM monitoring logic.
    - Updated `mmu.cfg` configuration for BLDC motors and belay sensor parameters.
    - Improved `multi_material_unit.py` with better tool and motor management, debug logging, and belay sensor callback logic.
    - Deleted obsolete STL files: `[a]_gt2_pulley_26t_x2.stl` and `[a]_gt2_pulley_32t_x2.stl` to clean up unused resources.
    [[a]_gt2_pulley_26t_x2.stl, [a]_gt2_pulley_32t_x2.stl, mmu.cfg]
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2025-11-26 Refactor deployment script and enhance MMU control algorithms
    - Renamed functions `scp` and `ssh` to `Invoke-SCP` and `Invoke-SSH` for clarity.
    - Implemented a limit on firmware restarts to prevent infinite loops.
    - Updated the handling of belay control logic with two new classes: `MMUControlBangBang` and `MMUControlPID`, allowing for more flexible control methods.
    - Enhanced `mmu.cfg` configuration to include `belay_control` method, `belay_max_delta`, and commented-out default PID parameters for easy adjustment.
    - Improved readability and maintained consistency in the `multi_material_unit.py` code structure.
    [mmu.cfg]
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
